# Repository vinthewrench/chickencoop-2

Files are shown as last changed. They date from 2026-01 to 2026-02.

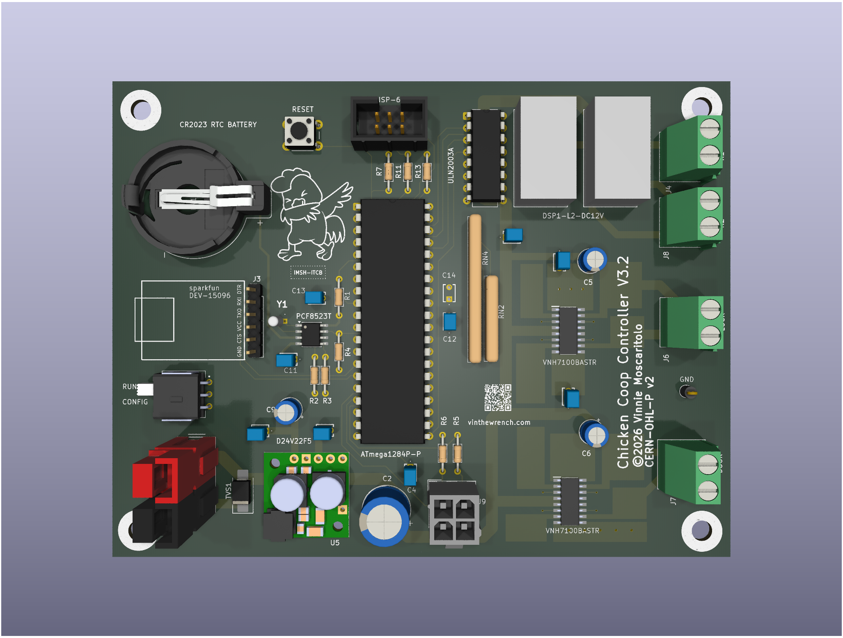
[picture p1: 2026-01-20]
hw/3.2/chickencoop3.2.png

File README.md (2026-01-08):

# Chicken Coop Controller

**Firmware and host-side tooling for an offline, solar-aware chicken coop controller based on the ATmega32U4.**

This repository contains:
- A **desktop host build** for testing and development
- An **AVR firmware build** for deployment
- A shared `src/` tree with no generated artifacts

The build system is intentionally explicit and boring:
- C++ only
- No generated files in `src/`
- All object files live under `build/`
- Host and firmware builds are independent

Hardware for this repository is frozen at **Chicken Coop Controller V3.0**.
Firmware and host code must conform to the shipped hardware.

---

## Repository Layout

```
├── Makefile
│   # Top-level build orchestrator
│   # Invokes host/ and firmware/ builds
│
├── README.md
│   # Project overview and build instructions
│
├── coop.cfg
│   # Example/default runtime configuration for host testing
│
├── firmware/
│   # AVR firmware for Chicken Coop Controller V3.0 (avr-g++)
│   ├── Makefile
│   │   # Firmware build rules
│   ├── main_firmware.cpp
│   │   # Firmware entry point (CONFIG + RUN)
│   │   # Shares scheduler/reducer/apply logic with host
│   └── platform/
│       # Board-specific AVR implementation (Hardware V3.0)
│       ├── config_eeprom.cpp
│       │   # Persistent configuration storage (EEPROM)
│       ├── config_sw_avr.cpp
│       │   # Hardware CONFIG switch handling
│       ├── console_io_avr.cpp
│       │   # AVR-side console I/O glue
│       ├── door_avr.cpp
│       │   # Door motor control (real hardware)
│       ├── door_led_avr.cpp
│       │   # Door LED driver (real hardware)
│       ├── door_lock_avr.cpp
│       │   # Lock actuator control (real hardware)
│       ├── relays_avr.cpp
│       │   # Relay pulse drivers (real hardware)
│       ├── rtc.cpp
│       │   # RTC implementation for PCF8523 (I2C)
│       ├── system_sleep_avr.cpp
│       │   # Low-power sleep implementation (AVR)
│       ├── uart.cpp
│       │   # UART service (console/debug)
│       ├── uart.h
│       ├── uptime.cpp
│       │   # System uptime service (AVR)
│       ├── i2c_avr.cpp
│       │   # I2C implementation (RTC, peripherals)
│       └── i2c.h
│
├── host/
│   # Desktop host build and test console (clang++)
│   ├── Makefile
│   ├── main_host.cpp
│   │   # Host entry point (interactive console + scheduler loop)
│   └── platform/
│       # Host-side implementations (no real hardware)
│       ├── config_host.cpp
│       ├── config_sw_host.cpp
│       ├── console_io_host.cpp
│       ├── door_hw_host.cpp
│       ├── door_led_host.cpp
│       ├── lock_hw_host.cpp
│       ├── relays_host.cpp
│       ├── rtc_host.cpp
│       ├── system_sleep_host.cpp
│       └── uptime_host.cpp
│
└── src/
    # Shared, platform-independent logic
    # No main(), no generated files, minimal platform assumptions
    ├── config.h
    ├── config_common.cpp
    ├── config_events.cpp
    ├── config_events.h
    ├── config_sw.h
    │
    ├── events.h
    ├── resolve_when.cpp
    ├── resolve_when.h
    ├── next_event.cpp
    ├── next_event.h
    │
    ├── rtc.h
    ├── rtc_common.cpp
    │
    ├── solar.cpp
    ├── solar.h
    │
    ├── time_dst.cpp
    ├── time_dst.h
    │
    ├── uptime.h
    │
    ├── scheduler.cpp
    ├── scheduler.h
    ├── state_reducer.cpp
    ├── state_reducer.h
    ├── schedule_apply.cpp
    ├── schedule_apply.h
    │
    ├── system_sleep.h
    │
    ├── door_hw.h
    ├── door_led.h
    ├── lock_hw.h
    ├── relay_hw.h
    │
    ├── console/
    │   # Shared console implementation
    │   ├── console.cpp
    │   ├── console.h
    │   ├── console_cmds.cpp
    │   ├── console_time.cpp
    │   ├── console_time.h
    │   ├── console_io.h
    │   ├── mini_printf.cpp
    │   └── mini_printf.h
    │
    └── devices/
        # Abstract device model layer + state machines
        ├── device.h
        ├── device_ids.h
        ├── devices.cpp
        ├── devices.h
        ├── door_device.cpp
        ├── door_state_machine.cpp
        ├── door_state_machine.h
        ├── lock_device.cpp
        ├── lock_state_machine.cpp
        ├── lock_state_machine.h
        ├── relay_device.cpp
        ├── led_device.cpp
        ├── led_state_machine.cpp
        ├── led_state_machine.h
        └── foo_device.cpp
```

### Rules
- `src/` must always remain clean
- No `.o`, `.elf`, `.hex`, or generated files under `src/`
- All build products live under `build/`
- Host and firmware builds do **not** share object files

---

## Top-Level Make Targets

Run all commands from the **repository root**.

```sh
make
make all
```
Builds **both** host and firmware (default).

```sh
make host
```
Builds **host console only**.

```sh
make firmware
```
Builds **AVR firmware only**.

```sh
make clean
```
Cleans host and firmware build outputs.

---

## Host Console (Desktop Test Environment)

### Purpose
The host build is a functional test harness for:
- Command parsing
- Solar and schedule calculations
- Configuration handling
- Console behavior
- Simulated RTC, EEPROM, relays, door, lock, and uptime

### Build
```sh
cd host
make
```

### Run
```sh
./build/console_host
```

### Exit
```
exit
```

The host build uses **clang++** and builds entirely under `host/build/`.

No source files live under `host/src/`. All shared logic comes from the top-level `src/` directory.

---

## Firmware (ATmega32U4)

### Build
```sh
cd firmware
make
```

### Outputs
```
coop_firmware.elf
coop_firmware.hex
coop_firmware.map
```

### Toolchain
- `avr-g++`
- Target MCU: **ATmega32U4**
- Clock: **Internal 8 MHz RC oscillator**

---

## Flashing (Atmel-ICE, ISP)

```sh
cd firmware
make flash
```

Assumptions:
- Atmel-ICE
- ISP mode
- USB transport
- No bootloader

---

## Fuse Management (LOCKED VALUES)

⚠️ **WARNING**  
Fuse settings are hardware configuration. Treat as write-once per board.

### Read fuses
```sh
cd firmware
make check-fuses
```

### Program fuses (ONLY on new or recovered chips)
```sh
cd firmware
make set-fuses
```

### Locked Fuse Values

| Fuse | Value | Meaning |
|-----:|:-----:|---|
| Low  | 0xFF  | Internal 8 MHz RC, CLKDIV8 disabled |
| High | 0xD8  | JTAG disabled, reset enabled |
| Ext  | 0xF5  | Brown-out detect ≈ 4.3 V |

These values are fixed by the hardware design and should not be changed casually.

---

## Time, Solar, and DST Behavior

- RTC runs in **local civil time**
- `tz` is the **standard time offset** (e.g. `-6` for Central)
- Daylight Saving Time is handled via **US rules (post-2007)**
- DST logic lives in `src/time_dst.cpp`
- DST is applied at the **solar computation boundary**, not inside the solar math itself

This system is fully offline and deterministic.

---

## Version Injection

### Single source of truth
Defined in the **top-level Makefile**:

Note: `PROJECT_VERSION` refers to the **firmware/software version**, not the hardware revision.
Hardware for this repository is **Chicken Coop Controller V3.0**.

```make
PROJECT_VERSION := 2.6.x
```

### Injected into builds as
```c++
PROJECT_VERSION
```

### Used for
- Startup banner
- `version` console command
- Debug output

---

## Sanity Check Workflow

From the repo root:

```sh
make clean
make
make host
make firmware
```

If this completes without errors, the build system is stable.

---

## Final Notes

- GNU Make **3.81 compatible**
- Relative paths used intentionally
- No clever build magic
- If something breaks, it’s real code, not glue

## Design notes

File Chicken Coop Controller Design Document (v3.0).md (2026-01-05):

<style>
@media print {
  body { font-family: Georgia, serif; line-height: 1.5; margin: 2cm; }
 /*h1 { page-break-before: always; } *//* New sections on new pages */
  pre, code { background: #f4f4f4; padding: 10px; }
  hr { page-break-after: always; visibility: hidden; }  /* Use --- for manual breaks */
}
</style>

# Standalone Chicken Coop Controller Design Document (v3.0)

**Date:** Jan 5, 2026  

**Sources of Truth:**  
- KiCad schematic (`chickencoop3.kicad_sch`)  
- Locked MCU pin assignments   

## 1. Purpose and Scope (Goal)

The controller automates chicken coop door operation in off-grid or remote setups by opening the door at **sunrise** and closing/securing it at **sunset**. This protects chickens from nocturnal predators while allowing free-range access during daylight hours.

Core design goals:  
- Fully **offline** — no internet, cloud, GPS, or external sensors.  
- One-time manual setup of date, time, latitude, and longitude by the farmer via serial console.  
- Months-long operation on a single 12V motorcycle-size SLA/AGM battery (typically 7–12 Ah).  
- Deterministic and fully inspectable behavior — all states observable via LED, multimeter, or serial console only.  
- Minimal components for maximum reliability and lowest possible power consumption.  

The system assumes a fixed geographic location and uses local standard time (no automatic DST handling).

## 2. How It Works (High-Level Overview)

1. **Initial Setup**  
   The farmer connects a serial console (e.g., via FTDI adapter) and uses simple text commands to set current date/time, latitude, longitude, and timezone offset. These values are stored persistently in the ATmega32U4 EEPROM.

2. **Normal Operation (RUN Mode)**  
   - The MCU spends >99% of its time in power-down sleep.  
   - It wakes via RTC alarm interrupt or manual door button press.  
   - On wake: reads current date/time from the PCF8523T RTC.  
   - Computes sunrise and sunset times for the current date using the stored location and the ported buelowp/sunset algorithm.  
   - If current time matches sunrise → opens door (extend actuator).  
   - If current time matches sunset → closes door (retract actuator), then pulses lock actuator.  
   - Programs the next RTC alarm (sunrise or sunset) and returns to sleep.  

3. **Manual Override**  
   Pressing the illuminated door button wakes the MCU and toggles the door state (open ↔ close + lock/unlock as needed).

4. **Status Indication**  
   The full-face illumination of the button actuator provides clear visual feedback (motion, locked, config needed, fault).

5. **Power Management**  
   12V battery powers actuators directly. The Pololu D24V22F5 switching regulator provides efficient 5V for logic with very low quiescent current.

Door position is inferred mechanically from the PA-14 actuator’s internal limit switches combined with firmware-enforced maximum runtimes. No external sensors are used.

Firmware is written in AVR C++, interrupt-driven, no RTOS, total size comfortably under 32 KB flash.

## 3. System Overview – Major Components

- **MCU**: ATmega32U4RC-AU (TQFP-44, internal RC oscillator)  
- **RTC**: PCF8523T (SOIC-8, I2C, alarm interrupt, CR2032 backup, 32.768 kHz crystal AB26T-32.768kHz)  
- **Door Actuator**: PA-14 linear actuator (12 V, internal non-adjustable limit switches)  
- **Lock Actuator**: Generic 12 V automotive door lock actuator (time-pulsed only)  
- **Motor Drivers**: 2 × VNH7100BASTR (INA/INB/EN control)  
- **5 V Regulator**: Pololu D24V22F5 (step-down switching regulator, 5.3–36 V input, 5 V @ up to 2.5 A output)  
- **Battery**: 12 V motorcycle-size sealed lead-acid or AGM  
- **User Interface / Status Indicator**: FL12DRG5 (EOZ) illuminated momentary pushbutton  
  - Integrates SPST-NO switch contact and full-face bi-color (red/green) LED at 5 V.  
  - Panel-mount (12 mm cutout), IP67 sealed, off-board via cable.

## 4. Power Architecture

- **Direct 12 V paths**: Battery → actuators (via motor drivers).  
- **5 V rail**: Pololu D24V22F5  
  - Input range: 5.3–36 V (ideal for 12 V SLA/AGM with charging margin).  
  - Output: 5 V @ up to 2.5 A.  
  - Quiescent current: ~1 mA (enabled).  
  - EN pin: Left unconnected (internal 270 kΩ pull-up to VIN keeps regulator enabled).  
  - Built-in protections: reverse-voltage, over-current, thermal shutdown.  

- **Sleep optimization**: Regulator remains enabled (EN floating). MCU enters power-down mode, achieving overall sleep current dominated by regulator's ~1 mA (acceptable for months-long battery life on 7–12 Ah capacity).  

- **Additional Recommended Components** (around D24V22F5):  
  - Input: 33–47 µF electrolytic (≥50 V) + 0.1–10 µF ceramic between VIN and GND (close to pins) for noise suppression on long battery leads.  
  - Output: 10–47 µF low-ESR capacitor (≥10 V) between VOUT and GND for load stability.  
  - PG pin: Optional 10–100 kΩ pull-up to +5 V if monitoring Power Good.  

- **Protection**:  
  - 5 A resettable polyfuse in series with battery positive.  
  - Reverse polarity protection built into D24V22F5.  

Target total sleep current: ~1 mA (yielding months of operation on a 7–12 Ah battery).

## 5. MCU Details and Locked Pin Assignments

**MCU Part Number**: ATmega32U4 (RC variant for internal oscillator)  
**Package**: 44-pin TQFP  
**Voltage**: 5 V  
**Source of truth for pinout**: Microchip Atmel-7766 Figure 1-1  

**MCU Specs**  
- Flash: 32 KB  
- SRAM: 2.5 KB  
- EEPROM: 1 KB  
- Clock: Internal RC  
- Voltage: 5 V  

**Locked Design Decisions**  
- Programming: AVR-ISP-6 only  
- USB: Not used (connector not populated, D+/D- NC)  
- RTC wake: External interrupt  
- Serial console: UART (USART1)  
- Door and lock drivers: 2 × VNH7100BASTR  
- All references use **physical pin numbers**  

**Boot/USB/Recovery**  
- Reflash method: ISP only (no DFU reliance)  
- HWB (PE2, Pin 33): Pulled HIGH (10 kΩ) to prevent accidental bootloader entry  

**Power Pins**  
- Pin 2: UVcc (USB supply – not used)  
- Pin 5: UGnd  
- Pin 6: UCap (USB regulator cap)  
- Pin 7: VBus (USB sense – NC)  
- Pin 14: VCC  
- Pin 15: GND  
- Pin 23: GND  
- Pin 24: AVCC  
- Pin 34: VCC  
- Pin 35: GND  
- Pin 42: AREF  
- Pin 43: GND  
- Pin 44: AVCC  
- Pin 13: RESET  

**Decoupling (Required)**  
- 0.1 µF ceramic at each supply pin group (VCC/AVCC/UVCC) placed close to MCU.  
- At least one local bulk capacitor (4.7–10 µF) near MCU supply.  

**Pin Assignments**

### ISP (AVR-ISP-6)
| Signal | Physical Pin | Port/Function |
|---|---|---|
| SCK | 9 | PB1 |
| MOSI | 10 | PB2 |
| MISO | 11 | PB3 |
| RESET  | 13 | RESET |
| VCC | 14 | VCC |
| GND | 15 | GND |

### I2C (PCF8523T RTC)
| Signal | Physical Pin | Port/Function | Notes |
|---|---|---|---|
| SCL | 18 | PD0 | 4.7 kΩ pull-up to +5 V |
| SDA | 19 | PD1 | 4.7 kΩ pull-up to +5 V |

**I2C Pull-ups**  
If the PCF8523T module has no built-in pull-ups, add 4.7 kΩ to +5 V on SCL/SDA.

### RTC Wake Interrupt
| Signal | Physical Pin | Port/Function | Notes |
|---|---|---|---|
| RTC_INT  | 12 | PB7 | 10 kΩ pull-up to VCC |

### Serial Console (e.g., SparkFun DEV-15096 compatible)
| Physical Pin | Port/Function | SparkFun Pin | Notes |
|---|---|---|---|
| 20 | PD2 / RXD1 | 3 (TXO) | Optional 1 kΩ series |
| 21 | PD3 / TXD1 | 2 (RXI) | Optional 1 kΩ series |
| GND | GND | 6 | |

No DTR, CTS, or VCC connection.

### Configuration Switch

| Signal | Physical Pin | Port/Function | Notes |
|---|---|---|---|
| CONGIG_SW  | 31 | PC6 | 10 kΩ pull-up to VCC |

- SPDT switch (one throw to GND, other NC)  
- Internal pull-up enabled  
- Sampled once at boot

### Door Pushbutton and Integrated Status LED (FL12DRG5)
**Part**: FL12DRG5 (EOZ illuminated momentary pushbutton, bi-color red/green, 5 V fixed LED).    
 - Test shows that @5v - 240Ω series,  Red  = ~11mA, Green = ~9ma

**Implementation**  
- The FL12DRG5 is mounted on the enclosure panel and connected to the PCB via a **4-pin cable and connector**.  
- This single part provides both the manual door override button **and** the sole status indicator (full-face illuminated actuator).  
- No separate status LED or dedicated LED driver is used.

**Connections** (via 4-pin connector/cable):
| Signal | MCU Pin (Physical) | Port | Notes |
|---|---|---|---|
| Switch signal (NO)  | Pin 28 | PB4  | Active low to GND, 220 Ω series + 0.1 µF debounce on PCB |
| Common GND | — | GND  | Shared for switch and LED cathode |
| Red LED anode | Pin 29 | PB5  | Direct drive (built-in limiting resistors) |
| Green LED anode | Pin 30 | PB6  | Direct drive (built-in limiting resistors) |

**Button Function**  
- Momentary press wakes MCU (PCINT7) and toggles door state (open ↔ close + lock/unlock as needed).

**LED Behavior** (full-face illumination of button actuator)  
Priority (highest first):

| Priority | Condition | LED Pattern (Button Face) | Meaning |
|---|---|---|---|
| 1 | Fault | Solid RED | Actuator timeout, invalid state, etc. |
| 2 | Config required | Solid YELLOW (red + green) | No valid location/date in EEPROM |
| 3 | Door motion | Blink @ 2 Hz:<br>• **RED** = closing<br>• **GREEN** = opening | Clear directional feedback |
| 4 | Door closed + locked | RED pulse every 15 s (20–30 ms on) | Nighttime confirmation |
| 5 | Idle (door open, daytime)  | LEDs completely OFF | Power saving |

This integrated approach reduces component count, wiring, and power draw while providing highly visible, directional status feedback directly on the button the farmer presses.

### VNH7100BASTR Motor Drivers
**Lock Driver**
| Signal | Physical Pin | Port |
|---|---|---|
| LOCK_INA | 41 | PF0  |
| LOCK_INB | 40 | PF1  |
| LOCK_EN  | 39 | PF4  |

**Door Driver**
| Signal | Physical Pin | Port |
|---|---|---|
| DOOR_INA | 38 | PF5  |
| DOOR_INB | 37 | PF6  |
| DOOR_EN  | 36 | PF7  |

**Relay Drivers (Optional)**
| Signal | Physical Pin | Port |
|---|---|---|
| RELAY_1_SET | 22 | PD5  |
| RELAY_1_RESET | 25 | PD4  |
| RELAY_2_SET | 26 | PD6  |
| RELAY_2_RESET | 27 | PD7  |

Notes:  
- PF pins require AVCC powered.  
- JTAG disabled (fuses) to free PF4–PF7.  
- Default firmware state: EN = 0, INA/INB = 0.

### Complete Pin Assignment Table
| Pin # | Port / Signal | Assigned Function |
|---|---|---|
| 1 | PE6 | Unused |
| 2 | UVcc | USB supply (not used) |
| 3 | D- | USB (NC) |
| 4 | D+ | USB (NC) |
| 5 | UGnd | USB ground |
| 6 | UCap | USB regulator cap |
| 7 | VBus | USB sense (NC) |
| 8 | PB0 | Unused |
| 9 | PB1 | ISP SCK |
| 10 | PB2 | ISP MOSI |
| 11 | PB3 | ISP MISO |
| 12 | PB7 | RTC_INT (INT6) |
| 13 | RESET | RESET |
| 14 | VCC | +5 V |
| 15 | GND | Ground |
| 16 | XTAL2 | Unused (RC clock) |
| 17 | XTAL1 | Unused (RC clock) |
| 18 | PD0 | I2C SCL |
| 19 | PD1 | I2C SDA |
| 20 | PD2 | UART RXD1 |
| 21 | PD3 | UART TXD1 |
| 22 | PD5 | RELAY_1_RESET |
| 23 | GND | Ground |
| 24 | AVCC | Analog supply |
| 25 | PD4 | RELAY_1_SET |
| 26 | PD6 | RELAY_2_SET |
| 27 | PD7 | RELAY_2_RESET |
| 28 | PB4 | DOOR_SW (FL12DRG5 switch) |
| 29 | PB5 | Red LED anode (FL12DRG5) |
| 30 | PB6 | Green LED anode (FL12DRG5) |
| 31 | PC6 | CONFIG_SW |
| 32 | PC7 | Unused |
| 33 | PE2 | HWB (pulled high) |
| 34 | VCC | +5 V |
| 35 | GND | Ground |
| 36 | PF7 | DOOR_EN |
| 37 | PF6 | DOOR_INB |
| 38 | PF5 | DOOR_INA |
| 39 | PF4 | LOCK_EN |
| 40 | PF1 | LOCK_INB |
| 41 | PF0 | LOCK_INA |
| 42 | AREF | Analog reference |
| 43 | GND | Ground |
| 44 | AVCC | Analog supply |

## 6. Sunrise/Sunset Computation

Algorithm ported from **buelowp/sunset** (https://github.com/buelowp/sunset – Mike Chirico’s sunrise.c).

- Inputs: year, month, day, latitude (signed decimal degrees), longitude (signed), manual timezone offset (hours).  
- Core calculations: Julian day → solar declination → equation of time → hour angle → local sunrise/sunset times.  
- Output: minutes past midnight for sunrise and sunset.  
- Porting notes for AVR:  
  - Use double-precision floating point (soft-float supported by avr-gcc).  
  - Or convert to fixed-point for smaller code/size if needed.  
  - Accuracy ±2–5 minutes (more than sufficient for coop use).  
  - Handles edge cases (polar day/night returns invalid → no event).  

## 7. Persistent Storage

Latitude, longitude, timezone offset, and initial date/time are stored in the **ATmega32U4’s 1 KB EEPROM** for persistence across full power loss.

## 8. RTC and Timekeeping

- PCF8523T runs continuously on CR2032 backup when main battery is removed.  
- Sole source of truth for date/time.  
- Firmware sets single alarm interrupt for next sunrise or sunset event.

## 9. Actuator Control Logic

- **Door (PA-14)**: Enable driver, set INA/INB direction, run until firmware timeout (suggested 30 s max) or internal limits stop current.  
- **Lock**: Enable driver, set direction, pulse 150–400 ms (max 500 ms), disable. Never left energized.  

Default driver state: EN = 0, INA/INB = 0.

## 10. Boot and Configuration

- Boot samples CONFIG_SW (PB4).  
- Grounded → CONFIG mode (serial console active).  
- Open → RUN mode.  
- CONFIG commands (text, 115200 8N1 suggested):  
  - `set date YYYY-MM-DD`  
  - `set time HH:MM:SS`  
  - `set lat ±DD.DDDD`  
  - `set long ±DDD.DDDD`  
  - `set tz ±HH` (timezone offset)  
  - `open` / `close` / `lock` / `unlock` (manual test)  
- 60 s inactivity → auto-enter RUN mode.

## 11. Sleep Strategy

- MCU in power-down mode.  
- Wake sources: RTC INT (PE6), door button (PB7/PCINT).  
- All unnecessary peripherals disabled.  
- Regulator remains enabled (EN floating).  

## 12. Bill of Materials (Key Electrical Items)

- ATmega32U4RC-AU  
- PCF8523T  
- 2 × VNH7100BASTR  
- Pololu D24V22F5 (5 V step-down regulator)  
- AB26T-32.768kHz crystal  
- CR2032 + holder  
- FL12DRG5 (EOZ) — illuminated momentary pushbutton, bi-color red/green, 5 V  
- Passives: resistors (4.7 k, 10 k, 220 Ω, etc.), capacitors (input/output for regulator, 0.1 µF decoupling ceramics, bulk caps), polyfuse  

## 13. Explicit Exclusions

- No sensors  
- No wireless  
- No cloud/GPS  
- No automatic DST  
- No encoders/feedback  
- No heartbeat LED  
- No separate status LED or LED driver IC  

## 14. Design Philosophy

If a state or behavior is not directly observable with an LED, multimeter, or serial console — it does not belong in this system.

Minimalism, inspectability, and battery life take priority over convenience features.

## 15. Firmware Overview (AVR C++)

Firmware is written in **AVR C++** (not plain C), compiled with **avr-gcc** (g++ mode), programmed via **Atmel-ICE (ISP mode)**, and built using a **Makefile**. No Arduino framework or libraries are used.

### Key Firmware Requirements
- Ultra-low power: MCU spends >99% of time in power-down sleep.
- Interrupt-driven only: No polling loops.
- Deterministic behavior: All actions triggered by RTC alarm or button press.
- Persistent configuration: Latitude, longitude, timezone offset stored in EEPROM (with CRC validation).
- Sunrise/sunset calculation using fixed-point port of buelowp/sunset algorithm.
- Simple text-based serial console in CONFIG mode.

### Startup Sequence (main() and Initialization)
```cpp
int main(void) {
    // 1. Disable watchdog (in case of previous reset)
    wdt_disable();

    // 2. Disable all unnecessary peripherals to minimize power
    PRR = (1 << PRTWI) | (1 << PRTIM0) | (1 << PRTIM1) | (1 << PRTIM2) |
          (1 << PRADC) | (1 << PRUSART0) | (1 << PRSPI);  // Keep USART1 for console

    // 3. Configure pins
    // Inputs with pull-ups
    DDRB &= ~((1 << PB7) | (1 << PB4));  // DOOR_SW and CONFIG_SW as inputs
    PORTB |= (1 << PB7) | (1 << PB4);    // Enable internal pull-ups

    // Outputs default low/off
    DDRB |= (1 << PB5) | (1 << PB6);     // LED control (red/green)
    DDRF |= (1 << PF7) | (1 << PF6) | (1 << PF5) |   // Door driver
            (1 << PF4) | (1 << PF1) | (1 << PF0);    // Lock driver
    PORTB &= ~((1 << PB5) | (1 << PB6));  // LEDs off
    PORTF &= ~((1 << PF7) | (1 << PF6) | (1 << PF5) |
               (1 << PF4) | (1 << PF1) | (1 << PF0));  // Drivers disabled

    // 4. Sample CONFIG_SW once (latched until reboot)
    bool config_mode = (PINB & (1 << PB4)) == 0;

    // 5. Initialize UART (only if config mode, but safe to init always)
    uart_init(115200);

    // 6. Initialize I2C and RTC
    i2c_init();
    rtc_init();  // Verify communication, set 32kHz output if needed

    // 7. Enable interrupts for wake sources
    PCICR |= (1 << PCIE0);        // Enable pin change interrupt on PCINT[7:0] (PB7)
    PCMSK0 |= (1 << PCINT7);      // Mask for PB7 (door button)
    EIMSK |= (1 << INT6);         // Enable INT6 on PE6 (RTC alarm)
    EIFR |= (1 << INTF6);         // Clear any pending flag

    sei();  // Global interrupt enable

    if (config_mode) {
        enter_config_mode();  // Blocking console loop with inactivity timeout
        // On exit: falls through to RUN mode
    }

    // 8. Load settings from EEPROM (validate with CRC)
    load_settings_from_eeprom();

    // 9. Enter normal RUN mode
    run_mode_loop();  // Never returns
}
```
### Sleep and Wake Strategy
```cpp
void enter_sleep() {
    // Turn off LEDs and drivers
    PORTB &= ~((1 << PB5) | (1 << PB6));
    PORTF &= ~((1 << PF7) | (1 << PF6) | (1 << PF5) |
               (1 << PF4) | (1 << PF1) | (1 << PF0));

    // Additional power reduction
    PRR |= (1 << PRTWI) | (1 << PRUSART1);  // Disable I2C & UART after use

    set_sleep_mode(SLEEP_MODE_PWR_DOWN);
    sleep_enable();
    sei();              // Ensure interrupts enabled before sleep
    sleep_cpu();        // Enter sleep — wakes on RTC INT or button PCINT
    sleep_disable();    // On wake

    // Re-enable peripherals as needed
    PRR &= ~((1 << PRTWI) | (1 << PRUSART1));
}
```
### RUN Mode Main Loop
```cpp
void run_mode_loop() {
    while (1) {
        // Read current date/time from RTC
        rtc_get_datetime(&current_time);

        // Compute sunrise/sunset for today
        compute_sunrise_sunset(current_time.year, current_time.month, current_time.day,
                               settings.lat, settings.lon, settings.tz,
                               &sunrise_min, &sunset_min);

        // Determine next event and program RTC alarm
        uint16_t next_alarm_min;
        if (should_open_now(&current_time, sunrise_min)) {
            open_door();
            next_alarm_min = sunset_min;
        } else if (should_close_now(&current_time, sunset_min)) {
            close_door_and_lock();
            next_alarm_min = sunrise_min;  // Tomorrow's sunrise
        } else {
            // Determine which is next
            next_alarm_min = closer_event(current_time.minutes_past_midnight(),
                                          sunrise_min, sunset_min);
        }

        rtc_set_alarm(next_alarm_min);

        // Update LED state (e.g., pulse if locked)
        update_status_led();

        enter_sleep();  // Sleep until next alarm or button press
    }
}
```
### Interrupt Service Routines
```cpp
ISR(INT6_vect) {
    // RTC alarm — cleared automatically by reading status register
    // Just wake — main loop handles action
}

ISR(PCINT0_vect) {
    if ((PINB & (1 << PB7)) == 0) {  // Button pressed (active low)
        // Debounce in main loop or simple delay
        manual_door_toggle();
    }
}
```
### Key Notes (Firmware)
- All heavy work (sunrise/sunset calculation, actuator drive, LED updates) is performed immediately after wake — the system returns to sleep as soon as possible.
- Serial console is active only in CONFIG mode (or optionally in background if needed for debugging).
- Faults are indicated via LED blink patterns (e.g., solid red on actuator timeout or RTC error).
- Avoid floating-point math if possible — use fixed-point arithmetic for the sunrise/sunset algorithm to reduce code size and execution time on the AVR.
- EEPROM writes are minimized: only on configuration changes (rare) to prevent wear.
- Power reduction registers (PRR) are used aggressively to disable unused peripherals before sleep.
- Interrupt service routines are kept minimal — heavy logic stays in the main loop for readability and debugging.

## 16. Technical Review (Deep Dive – v2.3)

This section provides a detailed technical review of the design as documented in v2.3. All claims are based on datasheets, calculations, and practical experience with similar systems.

### MCU and Pin Assignments
- **ATmega32U4RC-AU**: Excellent choice for low-power, offline work. Internal RC oscillator avoids external crystal power draw (~µA savings). Power-down sleep with PCINT and external interrupt enabled draws ~0.1–1 µA (datasheet Table 29-1).  
- **Pin usage**: Fully locked and conflict-free. PF4–PF7 freed by JTAG disable (fuses). Unused pins (PD4–PD7, PC6–PC7, PB0) should be configured as outputs low or inputs pull-up disabled to minimize leakage.  
- **Fuses recommended**:  
  - Low: 0xFF (8 MHz internal RC, no CLKDIV8)  
  - High: 0xD8 (JTAG disabled, boot size 0)  
  - Extended: 0xF5 (BOD ~4.3 V for 5 V stability)  
- **Risk**: No ADC used — disable in PRR to save ~100 µA potential. Internal RC calibration drift ±10% — irrelevant for timing (RTC is master).

### Power Architecture (Pololu D24V22F5)
- **Performance**: Synchronous buck, ~90–95% efficiency at 12 V → 5 V. Quiescent ~1 mA enabled (datasheet typical). EN floating = correct (internal pull-up).  
- **External caps**: Input 33–47 µF electrolytic + 0.1–10 µF ceramic recommended for long battery wires/actuator spikes. Output 10–47 µF low-ESR for transients.  
- **Sleep current**: Regulator dominates at ~1 mA → 720 mAh/month. On 7 Ah battery: ~9–10 months. On 12 Ah: 16+ months. Acceptable for goal.  
- **Protection**: Built-in reverse (-40 V), overcurrent, thermal. Polyfuse + optional SMAJ18A TVS on +12 V adds belt-and-suspenders.  
- **Alternative for lower quiescent**: TPS62825 (~4 µA) would extend life significantly, but D24V22F5 is proven and fits footprint—stick with it unless measured sleep >1.5 mA.

### RTC (PCF8523T)
- **Accuracy**: ±20 ppm crystal → ~1–2 min/year drift. Chickens don't care—sufficient.  
- **Backup**: CR2032 lasts 5–10 years at 0.5 µA.  
- **I2C**: Pull-ups 4.7 kΩ fine. Bus short traces to avoid capacitance issues.  
- **Wake**: INT1 to PE6 (INT6) perfect—level-sensitive in power-down.

### Sunrise/Sunset Algorithm
- **Port**: buelowp/sunset is solid NOAA-based. Fixed-point recommended for AVR (no FPU). Execution <10 ms. Accuracy ±2–5 min — more than enough.  
- **Edge cases**: Polar latitudes handled (return invalid → skip event).  
- **Optimization**: Precompute declination table in flash if flash space allows.

### Startup and Power-Restore Behavior

On startup or power restore, the system does not replay missed scheduled events.

Instead, the system computes the desired steady state for the current time based on the active configuration and converges to that state immediately.

This reconciliation process ensures safe, deterministic behavior and prevents unintended actuation caused by delayed or missed events.

For example:

If the configured door open time has passed but the close time has not, the door will be commanded open.

If the configured close time has passed, the door will be commanded closed, regardless of whether the open event was missed.

Past events are never retroactively executed. Only the correct state for the present time is enforced.

This behavior is by design and applies uniformly to all time-scheduled subsystems.

On startup or power restore, the system does not replay missed events.
It computes the desired steady state for the current time and converges to it.

### User Interface (FL12DRG5)
- **Integration**: Brilliant minimalism—one part for button + status. Full-face illumination highly visible.  
- **Current**: Built-in resistors ~10–20 mA/color. Patterns low-duty → average <<1 mA. Direct MCU drive safe (pins rated 20 mA recommended).  
- **Wiring**: 4-pin cable clean for panel mount. IP67 front seal perfect for coop.  
- **Risk**: Exact current unknown until measured—test sample and add series resistors if too bright/power-hungry.

### Actuator Control (VNH7100BASTR)
- **Capability**: Handles PA-14 stall (~1–2 A) and lock pulse easily. EN control allows clean off-state.  
- **Inference**: Mechanical limits + timeout = reliable without sensors.  
- **Risk**: Stuck actuator undetected—LED fault blink covers it (timeout triggers fault).

### Persistent Storage
- **EEPROM**: 1 KB plenty. Writes only on config changes → <10/year → zero wear concern.

### Sleep Strategy
- **Power-down**: Dominant draw is regulator ~1 mA. MCU/RTC/drivers negligible.  
- **Wake**: RTC INT + button PCINT — ideal. No polling.

### Firmware (AVR C++)
- **Build chain**: avr-gcc (g++), Makefile, Atmel-ICE ISP — clean, reproducible, no bloat.  
- **Structure**: Interrupt-driven, sleep-centric — correct for power.  
- **Robustness**: Add CRC on EEPROM read, timeout faults to LED.

### Overall Assessment
- **Strengths**: Minimal, inspectable, deterministic, low-power enough for goal.  
- **Weaknesses**: Regulator quiescent limits life to ~9–16 months (still fine). No over-the-air recovery if firmware bug (but ISP header allows field fix).  
- **Score**: 9/10 — production-ready after first-board test (focus on sleep current measurement and LED brightness).  

No showstoppers. Build the PCB.

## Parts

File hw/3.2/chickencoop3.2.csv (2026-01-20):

Id | Designator | Footprint | Quantity | Designation | Supplier and ref
1 | BT1 | BAT_1066 | 1 | 1066
2 | C13,C1,C10,C11,C7,C12,C3,C4,C8,C14 | RCER71H104K0DBH03A | 10 | .1uf
3 | R4,R1 | R_Axial_DIN0204_L3.6mm_D1.6mm_P7.62mm_Horizontal | 2 | 10K
4 | U4,U3 | SOIC127P600X175-16N | 2 | VNH7100BASTR
5 | C5,C6,C9 | CP_Radial_D5.0mm_P2.00mm | 3 | 47uf
6 | J4 | TerminalBlock_Phoenix_MKDS-1,5-2-5.08_1x02_P5.08mm_Horizontal | 1 | K1
7 | TP3 | 5000 | 1 | GND
8 | RN2 | R_Array_SIP7 | 1 | 100K
9 | J3 | PinHeader_1x06_P2.54mm_Vertical | 1 | Serial port
10 | U1 | DIP-40_W15.24mm | 1 | ATmega1284P-P
11 | U5 | MODULE_5V_2.5A_STEP-DOWN_D24V22F5 | 1 | D24V22F5
12 | R5 | R_Axial_DIN0204_L3.6mm_D1.6mm_P7.62mm_Horizontal | 1 | 240Ω
13 | R3 | R_Axial_DIN0204_L3.6mm_D1.6mm_P7.62mm_Horizontal | 1 | 4.7K
14 | RN4 | R_Array_SIP12 | 1 | 1K
15 | K2,K1 | DSP1-L2-DC12V | 2 | DSP1-L2-DC12V
16 | C2 | CP_Radial_D10.0mm_P5.00mm | 1 | 1000uf
17 | R13,R11,R7 | R_Axial_DIN0204_L3.6mm_D1.6mm_P7.62mm_Horizontal | 3 | 470Ω
18 | U2 | SOIC-8_3.9x4.9mm_P1.27mm | 1 | PCF8523T
19 | J8 | TerminalBlock_Phoenix_MKDS-1,5-2-5.08_1x02_P5.08mm_Horizontal | 1 | K2
20 | R2 | R_Axial_DIN0204_L3.6mm_D1.6mm_P7.62mm_Horizontal | 1 | 4.7k
21 | TVS1 | D_SMB_Handsoldering | 1 | P6SMB18A
22 | J7 | TerminalBlock_Phoenix_MKDS-1,5-2-5.08_1x02_P5.08mm_Horizontal | 1 | DOOR
23 | J9 | Molex_Mini-Fit_Jr_5566-04A_2x02_P4.20mm_Vertical | 1 | Mini‑Fit Jr
24 | R6 | R_Axial_DIN0204_L3.6mm_D1.6mm_P7.62mm_Horizontal | 1 | 220Ω
25 | J1 | powerpole | 1 | Power Pole
26 | J6 | TerminalBlock_Phoenix_MKDS-1,5-2-5.08_1x02_P5.08mm_Horizontal | 1 | LOCK
27 | SW1 | AS11CH | 1 | SW_SPST
28 | SW3 | SW_PUSH_6mm | 1 | RESET
29 | J2 | PinHeader_2x03_P2.54mm_Vertical | 1 | AVR-ISP-6
30 | Y1 | AB26T32768KHZ | 1 | AB26T-32.768KHZ
31 | U6 | DIP-16_W7.62mm | 1 | ULN2003A

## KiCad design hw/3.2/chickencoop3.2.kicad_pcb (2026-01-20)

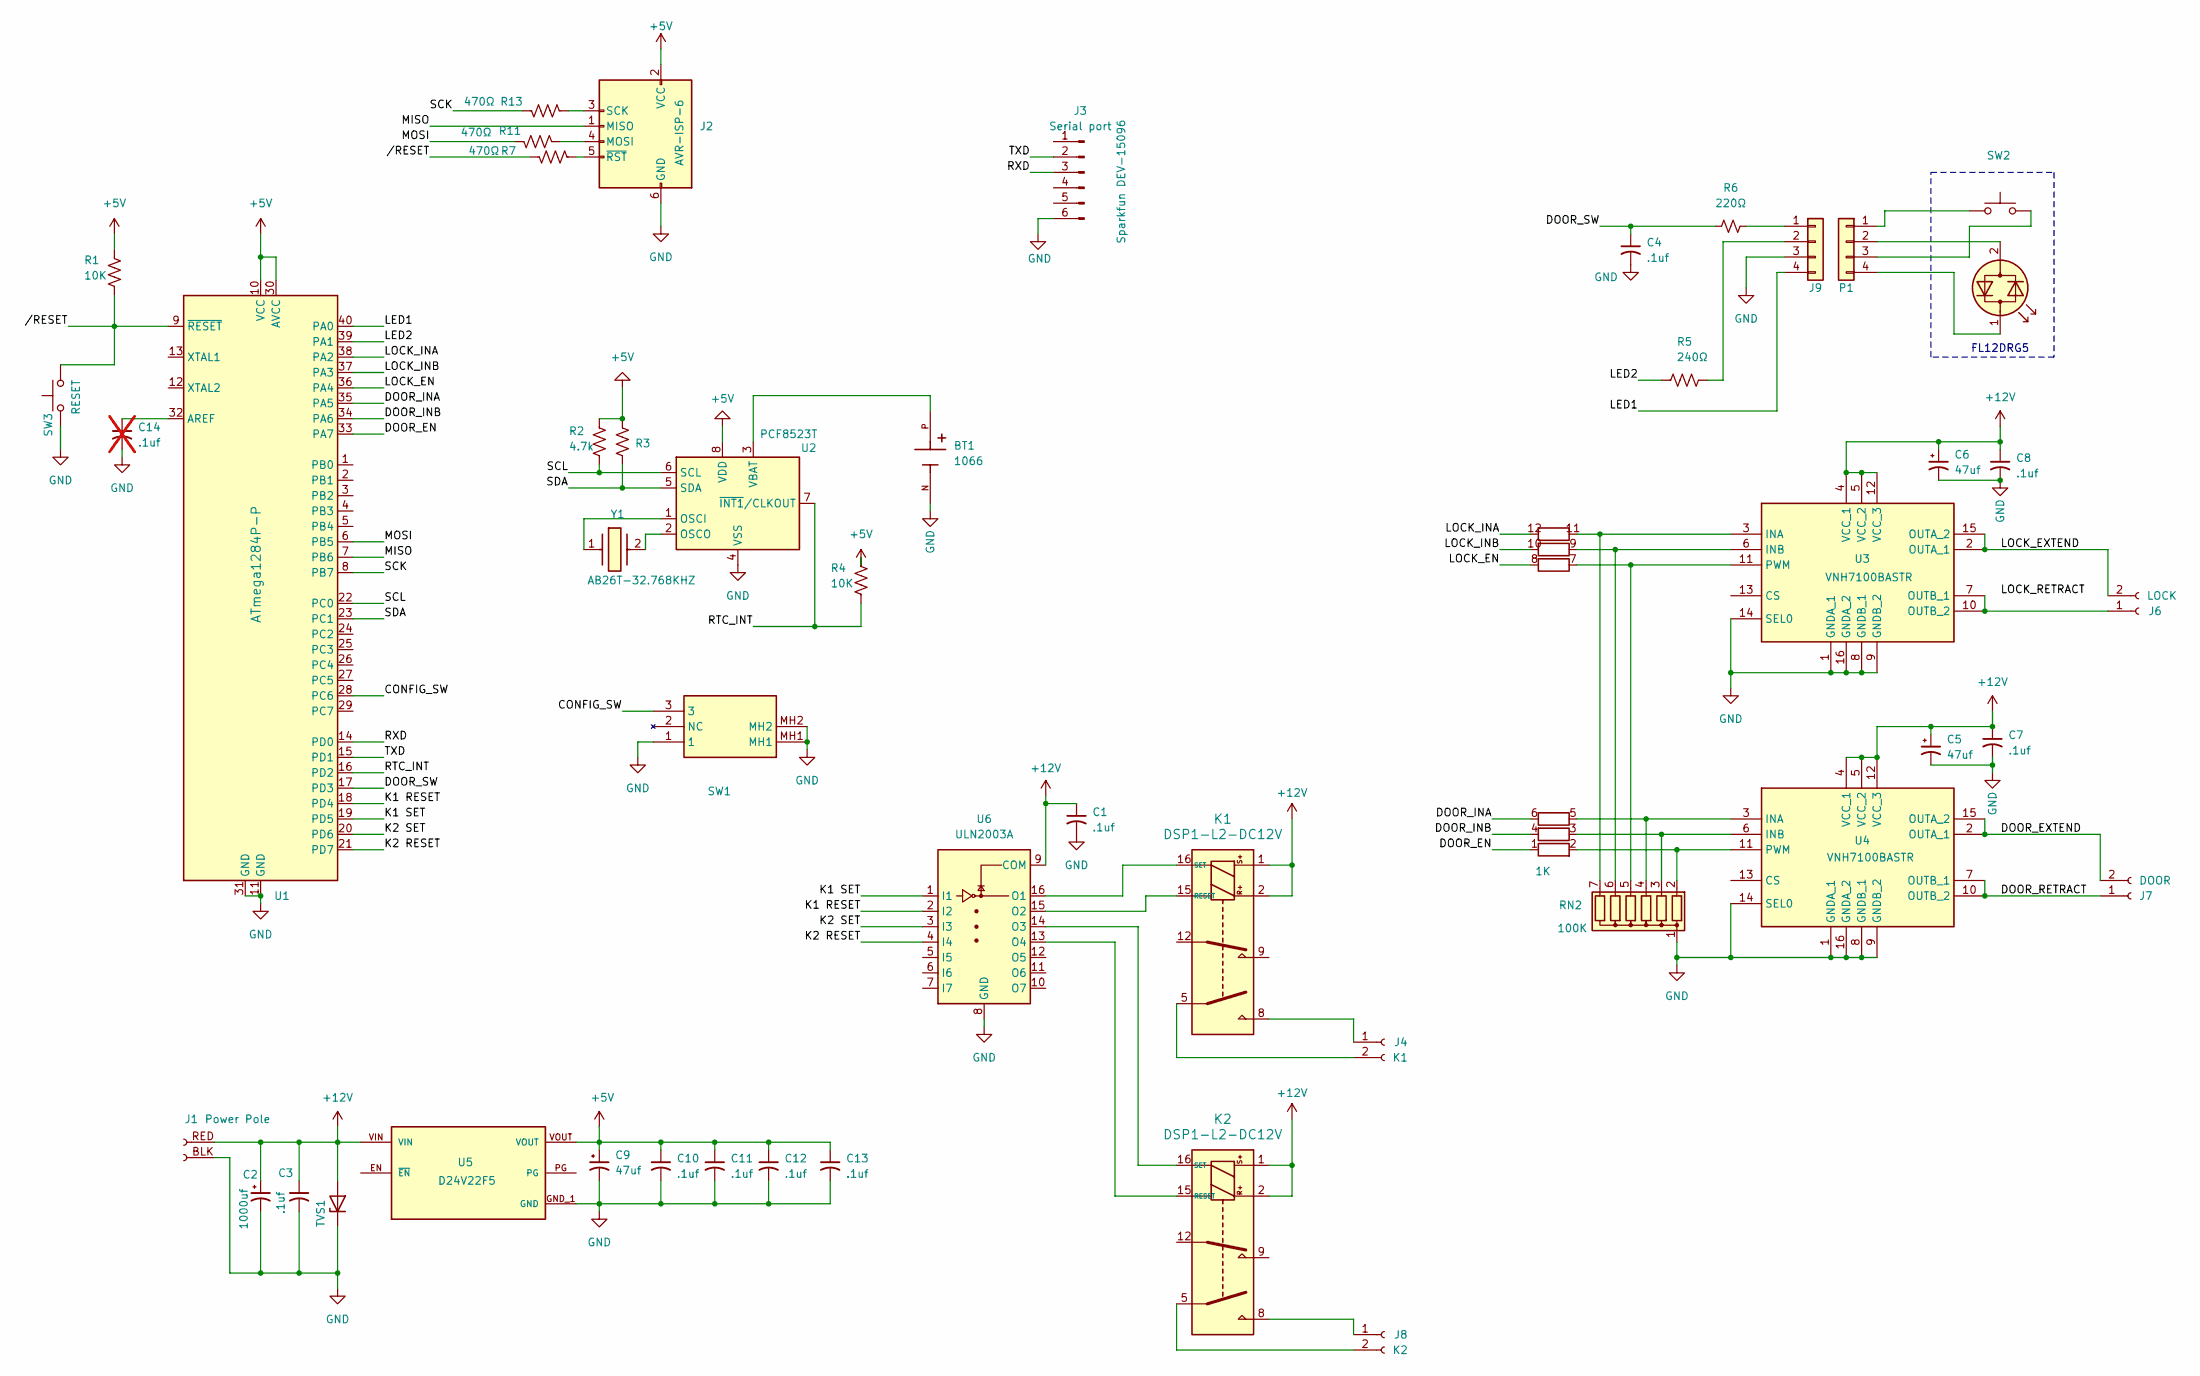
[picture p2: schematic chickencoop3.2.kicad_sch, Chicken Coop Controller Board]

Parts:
BT1: 1066; BAT_1066; PARTREV E
C1, C3, C4, C7, C8, C10, C11, C12, C13: .1uf; RCER71H104K0DBH03A
C2: 1000uf; CP_Radial_D10.0mm_P5.00mm
C5, C6, C9: 47uf; CP_Radial_D5.0mm_P2.00mm
C14: .1uf; RCER71H104K0DBH03A; not fitted
D1: LED_Dual_Bidirectional
J1: Power Pole; powerpole
J2: AVR-ISP-6; PinHeader_2x03_P2.54mm_Vertical
J3: Serial port; PinHeader_1x06_P2.54mm_Vertical
J4: K1; TerminalBlock_Phoenix_MKDS-1,5-2-5.08_1x02_P5.08mm_Horizont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
J6: LOCK; TerminalBlock_Phoenix_MKDS-1,5-2-5.08_1x02_P5.08mm_Horizont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
J7: DOOR; TerminalBlock_Phoenix_MKDS-1,5-2-5.08_1x02_P5.08mm_Horizont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
J8: K2; TerminalBlock_Phoenix_MKDS-1,5-2-5.08_1x02_P5.08mm_Horizont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
J9: Mini‑Fit Jr; Molex_Mini-Fit_Jr_5566-04A_2x02_P4.20mm_Vertical
K1, K2: DSP1-L2-DC12V
P1: Mini‑Fit Jr; Molex_Mini-Fit_Jr_5566-04A_2x02_P4.20mm_Vertical
R1, R4: 10K; R_Axial_DIN0204_L3.6mm_D1.6mm_P7.62mm_Horizontal
R2: 4.7k; R_Axial_DIN0204_L3.6mm_D1.6mm_P7.62mm_Horizontal
R3: 4.7K; R_Axial_DIN0204_L3.6mm_D1.6mm_P7.62mm_Horizontal
R5: 240Ω; R_Axial_DIN0204_L3.6mm_D1.6mm_P7.62mm_Horizontal
R6: 220Ω; R_Axial_DIN0204_L3.6mm_D1.6mm_P7.62mm_Horizontal
R7, R11, R13: 470Ω; R_Axial_DIN0204_L3.6mm_D1.6mm_P7.62mm_Horizontal
RN2: 100K; R_Array_SIP7; Manufacturer_Part_Number 4607X-101-104LF
RN4: 1K; R_Array_SIP12; Manufacturer_Part_Number 4612X-102-102LF
SW1: SW_SPST; AS11CH; Mouser Part Number 633-AS11CH
SW2: SW_Push
SW3: RESET; SW_PUSH_6mm
TVS1: P6SMB18A; D_SMB_Handsoldering
U1: ATmega1284P-P; DIP-40_W15.24mm
U2: PCF8523T; SOIC-8_3.9x4.9mm_P1.27mm
U3, U4: VNH7100BASTR; SOIC127P600X175-16N; Manufacturer_Part_Number VNH7100BASTR; Mouser Part Number 511-VNH7100BASTR
U5: D24V22F5; MODULE_5V_2.5A_STEP-DOWN_D24V22F5; PARTREV 12 November 2015
U6: ULN2003A; DIP-16_W7.62mm
Y1: AB26T-32.768KHZ; AB26T32768KHZ; Mouser Part Number 815-AB26T-32.768KHZ

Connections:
+5V: C9.1, C10.1, C11.1, C12.1, C13.1, J2.2 (VCC), R1.1, R2.1, R3.1, R4.1, U1.10 (VCC), U1.30 (AVCC), U2.8 (VDD), U5.VOUT
+12V: C1.1, C2.1, C3.1, C5.1, C6.1, C7.1, C8.1, J1.RED, K1.1, K1.2, K2.1, K2.2, TVS1.2 (A), U3.4 (VCC_1), U3.5 (VCC_2), U3.12 (VCC_3), U4.4 (VCC_1), U4.5 (VCC_2), U4.12 (VCC_3), U5.VIN, U6.9 (COM)
/CONFIG_SW: SW1.3, U1.28 (PC6)
/DOOR_EN: RN4.1 (R1.1), U1.33 (PA7)
/DOOR_EXTEND: J7.2, U4.2 (OUTA_1), U4.15 (OUTA_2)
/DOOR_INA: RN4.6 (R3.2), U1.35 (PA5)
/DOOR_INB: RN4.4 (R2.2), U1.34 (PA6)
/DOOR_RETRACT: J7.1, U4.7 (OUTB_1), U4.10 (OUTB_2)
/DOOR_SW: C4.1, R6.1, U1.17 (PD3)
/K1 RESET: U1.18 (PD4), U6.2 (I2)
/K1 SET: U1.19 (PD5), U6.1 (I1)
/K2 RESET: U1.21 (PD7), U6.4 (I4)
/K2 SET: U1.20 (PD6), U6.3 (I3)
/LED1: J9.4, U1.40 (PA0)
/LED2: R5.1, U1.39 (PA1)
/LOCK_EN: RN4.8 (R4.2), U1.36 (PA4)
/LOCK_EXTEND: J6.2, U3.2 (OUTA_1), U3.15 (OUTA_2)
/LOCK_INA: RN4.12 (R6.2), U1.38 (PA2)
/LOCK_INB: RN4.10 (R5.2), U1.37 (PA3)
/MISO: J2.1 (MISO), U1.7 (PB6)
/MOSI: R11.1, U1.6 (PB5)
/RTC_INT: R4.2, U1.16 (PD2), U2.7 (~INT1/CLKOUT)
/RXD: J3.3, U1.14 (PD0)
/SCK: R13.1, U1.8 (PB7)
/SCL: R2.2, U1.22 (PC0), U2.6 (SCL)
/SDA: R3.2, U1.23 (PC1), U2.5 (SDA)
/TXD: J3.2, U1.15 (PD1)
//RESET: R1.2, R7.1, SW3.2, U1.9 (~RESET)
GND: BT1.N, C1.2, C2.2, C3.2, C4.2, C5.2, C6.2, C7.2, C8.2, C9.2, C10.2, C11.2, C12.2, C13.2, C14.2, J1.BLK, J2.6 (GND), J3.6, J9.3, RN2.1 (common), SW1.1, SW1.MH1, SW1.MH2, SW3.1, TVS1.1 (K), U1.11 (GND), U1.31 (GND), U2.4 (VSS), U3.1 (GNDA_1), U3.8 (GNDB_1), U3.9 (GNDB_2), U3.14 (SEL0), U3.16 (GNDA_2), U4.1 (GNDA_1), U4.8 (GNDB_1), U4.9 (GNDB_2), U4.14 (SEL0), U4.16 (GNDA_2), U5.GND_1 (GND), U5.GND_2 (GND), U6.8 (GND)
unnamed: D1.1 (KA), P1.4
unnamed: D1.2 (AK), P1.2
unnamed: J2.4 (MOSI), R11.2
unnamed: J2.3 (SCK), R13.2
unnamed: J2.5 (~RST), R7.2
unnamed: J4.1, K1.8
unnamed: J4.2, K1.5
unnamed: J6.1, U3.7 (OUTB_1), U3.10 (OUTB_2)
unnamed: J8.1, K2.8
unnamed: J8.2, K2.5
unnamed: J9.1, R6.2
unnamed: J9.2, R5.2
unnamed: K1.15 (RESET), U6.15 (O2)
unnamed: K1.16 (SET), U6.16 (O1)
unnamed: K2.15 (RESET), U6.13 (O4)
unnamed: K2.16 (SET), U6.14 (O3)
unnamed: P1.1, SW2.1
unnamed: P1.3, SW2.2
unnamed: RN2.2 (R1), RN4.2 (R1.2), U4.11 (PWM)
unnamed: RN2.3 (R2), RN4.3 (R2.1), U4.6 (INB)
unnamed: RN2.4 (R3), RN4.5 (R3.1), U4.3 (INA)
unnamed: RN2.5 (R4), RN4.7 (R4.1), U3.11 (PWM)
unnamed: RN2.6 (R5), RN4.9 (R5.1), U3.6 (INB)
unnamed: RN2.7 (R6), RN4.11 (R6.1), U3.3 (INA)
unnamed: C14.1, U1.32 (AREF)
unnamed: U2.1 (OSCI), Y1.1
unnamed: U2.2 (OSCO), Y1.2
unnamed: BT1.P, U2.3 (VBAT)

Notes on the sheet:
FL12DRG5

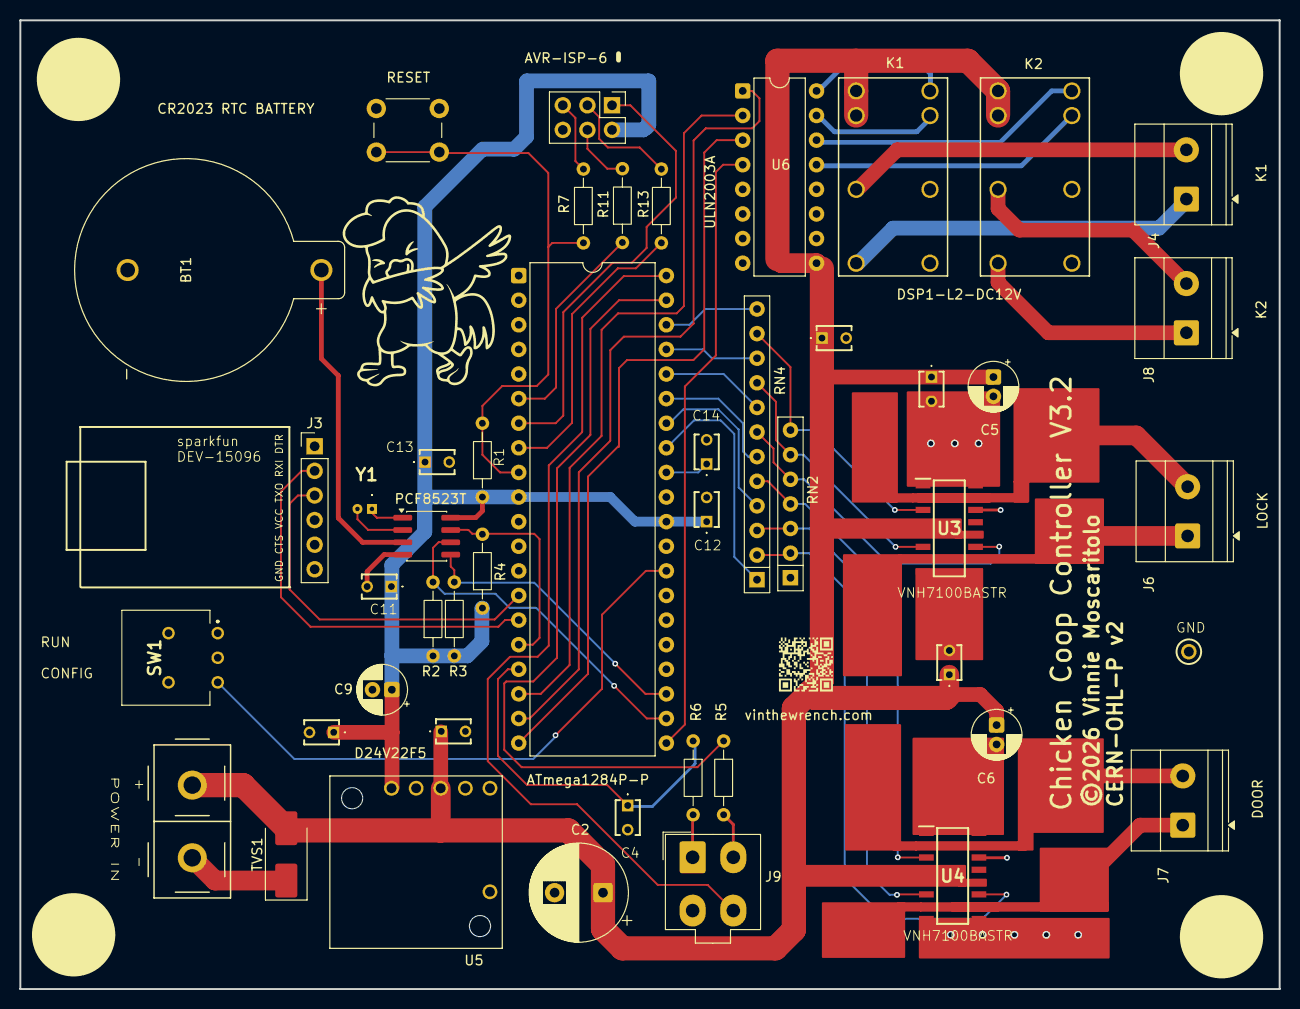
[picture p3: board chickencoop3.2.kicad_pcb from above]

Board: 2 copper layers, 130.0 x 100.0 mm, 47 parts (0 on the bottom side), 53 nets.

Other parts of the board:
TP3: GND; 5000

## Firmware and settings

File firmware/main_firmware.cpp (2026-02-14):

/*
 * main_firmware.cpp
 *
 * Chicken Coop Controller
 *
 * WAKE TRUTH:
 *   RTC INT → PD2 (INT0)
 *   LOW-level trigger
 *   SLEEP_MODE_PWR_DOWN
 *
 * Anything else is wrong.
 *
 * Updated: 2026-02-12
 */

#include <stdbool.h>
#include <stdint.h>
#include <util/delay.h>
#include <avr/io.h>
#include <avr/wdt.h>
#include <avr/interrupt.h>

#include "config.h"
#include "config_sw.h"

#include "console/console.h"
#include "console/mini_printf.h"

#include "uptime.h"
#include "rtc.h"
#include "solar.h"
#include "platform/uart.h"
#include "system_sleep.h"

#include "time_dst.h"

#include "scheduler.h"
#include "state_reducer.h"
#include "schedule_apply.h"

#include "devices/devices.h"
#include "devices/led_state_machine.h"
#include "devices/door_state_machine.h"

#include "platform/gpio_avr.h"
#include "platform/i2c.h"


/* ============================================================================
 * INT0 WAKE (PD2)
 * ========================================================================== */

ISR(INT0_vect)
{
    EIMSK &= (uint8_t)~(1u << INT0);
}

static volatile uint8_t g_door_event = 0;

ISR(INT1_vect)
{
    EIMSK &= (uint8_t)~(1u << INT1);
    g_door_event = 1u;
}


/* ============================================================================
 * TIME HELPERS
 * ========================================================================== */

static inline uint16_t minute_of_day(int h, int m)
{
    return (uint16_t)((uint16_t)h * 60u + (uint16_t)m);
}

static inline uint16_t next_minute(uint16_t now_min)
{
    return (uint16_t)((now_min + 1u) % 1440u);
}

static inline uint16_t strictly_future_minute(uint16_t now_min,
                                              uint16_t target_min)
{
    if (target_min <= now_min)
        return next_minute(now_min);
    return target_min;
}


/* ============================================================================
 * RESET CAUSE
 * ========================================================================== */

static uint8_t g_reset_flags;

static void reset_cause_capture_early(void)
{
    g_reset_flags = MCUSR;
    MCUSR = 0;
    wdt_disable();

    MCUCR |= _BV(JTD);
    MCUCR |= _BV(JTD);
}

static void reset_cause_debug_print(void)
{
    if (g_reset_flags & _BV(PORF))  mini_printf("RESET: Power On\n");
    if (g_reset_flags & _BV(BORF))  mini_printf("RESET: Brown-Out\n");
    if (g_reset_flags & _BV(WDRF))  mini_printf("RESET: Watchdog\n");
}


/* ============================================================================
 * MAIN
 * ========================================================================== */

 int main(void)
 {
     bool rtc_valid = false;

     reset_cause_capture_early();

     if (g_reset_flags & _BV(BORF)) {
         _delay_ms(50);
     }

     uart_init();
     uptime_init();
     coop_gpio_init();

     if (!i2c_init(100000)) {
         led_state_machine_init();
         led_state_machine_set(LED_BLINK, LED_RED);
         for (;;) {
             led_state_machine_tick(uptime_millis());
         }
     }

     rtc_init();

    rtc_valid = rtc_validate_at_boot();

     system_sleep_init();
     sei();

     device_init();
     scheduler_init();
     (void)config_load(&g_cfg);

     led_state_machine_set(LED_BLINK, LED_GREEN, 4);

     int last_y  = -1;
     int last_mo = -1;
     int last_d  = -1;

     uint16_t last_minute = 0xFFFF;
     uint32_t last_etag   = 0;

     struct solar_times sol;
     bool have_sol = false;

     bool in_config_mode = false;

     uint8_t  door_debounce_active   = 0;
     uint32_t door_debounce_start_ms = 0;

     bool force_time_read = true;

     int cached_y = 0, cached_mo = 0, cached_d = 0;
     int cached_h = 0, cached_m = 0, cached_s = 0;

     for (;;) {

         uint32_t now_ms = uptime_millis();
         device_tick(now_ms);

         /* ------------------------------------------------------
          * CONFIG switch
          * ------------------------------------------------------ */

         bool raw = config_sw_state();

         if (raw != in_config_mode) {

             _delay_ms(75);

             if (config_sw_state() == raw) {

                 in_config_mode = raw;

                 if (in_config_mode) {
                     console_init();
                     reset_cause_debug_print();
                 } else {
                     mini_printf("Exiting console\n\n");
                     console_flush();
                     console_terminal_shutdown();
                 }
             }
         }

         if (in_config_mode) {
             console_poll();
         }

         /* ------------------------------------------------------
          * Door ISR latch
          * ------------------------------------------------------ */

         if (g_door_event && !door_debounce_active) {
             g_door_event = 0u;
             door_debounce_active = 1u;
             door_debounce_start_ms = now_ms;
         }

         if (door_debounce_active) {
             if ((uint32_t)(now_ms - door_debounce_start_ms) >= 20u) {
                 door_debounce_active = 0u;
                 if (gpio_door_sw_is_asserted()) {
                     door_sm_toggle();
                 }
             }
         }

         if (!gpio_door_sw_is_asserted() && !door_debounce_active) {
             EIFR  |= (uint8_t)(1u << INTF1);
             EIMSK |= (uint8_t)(1u << INT1);
         }

         /* ------------------------------------------------------
          * RTC required
          * ------------------------------------------------------ */

          if(rtc_time_is_set()) {
              if(!rtc_valid) rtc_valid = true;
          }
          else
         {
             led_state_machine_set(LED_BLINK, LED_RED);
             continue;
         }

         /* ------------------------------------------------------
          * Read RTC ONLY when needed
          * ------------------------------------------------------ */

         if (force_time_read) {

             rtc_get_time(&cached_y,
                          &cached_mo,
                          &cached_d,
                          &cached_h,
                          &cached_m,
                          &cached_s);

             force_time_read = false;
         }

         uint16_t now_minute = minute_of_day(cached_h, cached_m);
         uint32_t cur_etag   = schedule_etag();

         bool minute_changed = (now_minute != last_minute);
         bool schedule_dirty = (cur_etag != last_etag);

         /* ------------------------------------------------------
          * On minute change, refresh RTC + scheduler
          * ------------------------------------------------------ */

         if (minute_changed || schedule_dirty) {

             /* Re-read RTC once to get accurate minute boundary */
             rtc_get_time(&cached_y,
                          &cached_mo,
                          &cached_d,
                          &cached_h,
                          &cached_m,
                          &cached_s);

             now_minute = minute_of_day(cached_h, cached_m);

             last_minute = now_minute;
             last_etag   = cur_etag;

             /* ---- Solar recompute if date changed ---- */

             if (cached_y != last_y ||
                 cached_mo != last_mo ||
                 cached_d != last_d) {

                 have_sol = false;

                 if (g_cfg.latitude_e4 != 0 ||
                     g_cfg.longitude_e4 != 0) {

                     double lat = (double)g_cfg.latitude_e4  / 10000.0;
                     double lon = (double)g_cfg.longitude_e4 / 10000.0;

                     int tz = g_cfg.tz;
                     if (g_cfg.honor_dst &&
                         is_us_dst(cached_y,
                                   cached_mo,
                                   cached_d,
                                   cached_h))
                         tz += 1;

                     have_sol = solar_compute(
                         cached_y, cached_mo, cached_d,
                         lat, lon,
                         (int8_t)tz,
                         &sol
                     );
                 }

                 scheduler_update_day(
                     cached_y, cached_mo, cached_d,
                     have_sol ? &sol : NULL,
                     have_sol
                 );

                 last_y  = cached_y;
                 last_mo = cached_mo;
                 last_d  = cached_d;
             }

             /* ---- Apply schedule ---- */

             struct reduced_state rs;

             size_t used = 0;
             const Event *events = config_events_get(&used);

             if (events && used > 0) {

                 state_reducer_run(
                     events,
                     MAX_EVENTS,
                     have_sol ? &sol : NULL,
                     now_minute,
                     &rs
                 );

                 schedule_apply(&rs);
             }
         }

         /* ------------------------------------------------------
          * Sleep only in RUN mode
          * ------------------------------------------------------ */

         if (in_config_mode)
             continue;

         if (devices_busy() ||
             door_debounce_active ||
             g_door_event)
             continue;

         uint16_t next_min;
         uint16_t wake_min;

         if (scheduler_next_event_minute(&next_min))
             wake_min = strictly_future_minute(now_minute, next_min);
         else
             wake_min = next_minute(now_minute);

         (void)rtc_alarm_set_minute_of_day(wake_min);
         system_sleep_until(wake_min);

         /* After wake, force time read next loop */
         force_time_read = true;

         if (gpio_rtc_int_is_asserted())
             rtc_alarm_clear_flag();

         EIFR |= (uint8_t)((1u << INTF0) | (1u << INTF1));

         if (!gpio_rtc_int_is_asserted())
             EIMSK |= (uint8_t)(1u << INT0);

         if (!gpio_door_sw_is_asserted())
             EIMSK |= (uint8_t)(1u << INT1);
     }
 }

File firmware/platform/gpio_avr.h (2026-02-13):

/*
 * gpio_avr.h
 *
 * Project: Chicken Coop Controller
 * Purpose: AVR GPIO pin definitions and low-level hardware mapping
 *
 * This header defines the canonical mapping between AVR GPIO pins
 * and physical hardware functions on the Chicken Coop Controller PCB.
 *
 * IMPORTANT DESIGN RULES:
 *  - All mappings in this file are LOCKED to the board schematic.
 *  - Do NOT rename, repurpose, or reassign any pin here unless
 *    the PCB schematic and layout are changed accordingly.
 *  - Higher-level code MUST treat these as hardware truth.
 *
 * SAFETY NOTE:
 *  - Several pins in this file control motors, relays, and solenoids.
 *  - Incorrect initialization or prolonged activation CAN damage hardware.
 *  - All outputs must be initialized to a known-safe OFF state at boot.
 *
 * Updated:
 *   (fill in date when pin mapping changes — not for code-only edits)
 */

#pragma once

/* --------------------------------------------------------------------------
 * Status LED Outputs
 * --------------------------------------------------------------------------
 *
 * These pins drive the front-panel red/green status LED through
 * external driver hardware.
 *
 * Naming convention:
 *  - LED_IN1 / LED_IN2 match the schematic net names.
 *  - Color association is documented for human clarity only.
 *
 * NOTE:
 *  - Do NOT change these names unless the hardware wiring changes.
 * -------------------------------------------------------------------------- */
 #define LED_IN1_BIT   PA1   /* RED   */
 #define LED_IN2_BIT   PA0   /* GREEN */

/* --------------------------------------------------------------------------
 * Door Motor H-Bridge Control (VNH7100BASTR)
 * --------------------------------------------------------------------------
 *
 * This H-bridge drives the main chicken coop door actuator.
 *
 * Electrical notes:
 *  - The door actuator includes internal end-of-travel limit switches.
 *  - Despite this, firmware MUST still enforce a maximum travel time
 *    as a fail-safe against wiring or switch failure.
 *
 * Pin behavior:
 *  - DOOR_EN   : Enables/disables the H-bridge (active HIGH)
 *  - DOOR_INA  : Direction control A
 *  - DOOR_INB  : Direction control B
 *
 * Reset behavior:
 *  - DOOR_EN MUST be driven LOW at boot.
 *  - INA/INB MUST be driven LOW at boot.
 *
 * -------------------------------------------------------------------------- */
/* DOOR_INA -> PF5 (physical pin 38) */
/* DOOR_INB -> PF6 (physical pin 37) */
/* DOOR_EN  -> PF7 (physical pin 36) */
#define DOOR_INA_BIT   PA5
#define DOOR_INB_BIT   PA6
#define DOOR_EN_BIT    PA7

/* --------------------------------------------------------------------------
 * Door Lock Actuator H-Bridge (VNH7100BASTR)
 * --------------------------------------------------------------------------
 *
 * This H-bridge drives the door LOCK actuator.
 *
 * CRITICAL SAFETY WARNING:
 *  - The lock actuator does NOT have end-of-travel limit switches.
 *  - It MUST be driven using a SHORT, FIXED-DURATION PULSE ONLY.
 *  - Continuous drive WILL overheat and destroy the actuator.
 *
 * Firmware requirements:
 *  - LOCK_EN MUST never be left asserted continuously.
 *  - A hard maximum pulse time (lock_pulse_ms) is mandatory.
 *  - Lock control must be edge-triggered, not state-held.
 *
 * JTAG NOTE:
 *  - LOCK_EN uses PF4, which is a JTAG pin by default.
 *  - Runtime JTAG disable is REQUIRED before driving this pin.
 * -------------------------------------------------------------------------- */
/* LOCK_INA -> PF0 */
/* LOCK_INB -> PF1 */
/* LOCK_EN  -> PF4 */
#define LOCK_INA_BIT   PA2
#define LOCK_INB_BIT   PA3
#define LOCK_EN_BIT    PA4

/* --------------------------------------------------------------------------
 * Latching Relay Outputs
 * --------------------------------------------------------------------------
 *
 * These pins drive a dual latching relay via external driver circuitry.
 *
 * Relay behavior:
 *  - SET and RESET are separate coils.
 *  - Coils must be pulsed briefly; they must NOT be held energized.
 *
 * Firmware requirements:
 *  - All relay outputs must default to OFF at boot.
 *  - Pulse duration must be limited in software.
 * -------------------------------------------------------------------------- */
#define RELAY1_SET_BIT    PD5
#define RELAY1_RESET_BIT  PD4
#define RELAY2_SET_BIT    PD6
#define RELAY2_RESET_BIT  PD7
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

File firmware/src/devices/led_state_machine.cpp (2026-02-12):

/*
 * led_state_machine.cpp
 *
 * Project: Chicken Coop Controller
 * Purpose: Door status LED state machine
 *
 * Notes:
 *  - Non-blocking at the state-machine level
 *  - Software PWM carrier is driven by repeated door_led_tick() calls
 *  - Pulse envelope is rate-limited for smooth breathing
 *
 * Extended:
 *  - Blink/Pulse may run finite number of cycles
 *  - count = 0 → infinite
 *  - count > 0 → run exactly N cycles then auto-off
 */

#include "led_state_machine.h"
#include "door_led.h"

#include <stdint.h>
#include <stdbool.h>

/* --------------------------------------------------------------------------
 * Timing
 * -------------------------------------------------------------------------- */

#define BLINK_PERIOD_MS   250u
#define PULSE_PERIOD_MS  1500u
#define PWM_TICKS_PER_MS  48u

/* --------------------------------------------------------------------------
 * Internal state
 * -------------------------------------------------------------------------- */

static led_mode_t  g_mode  = LED_OFF;
static led_color_t g_color = LED_GREEN;

/* Optional finite-cycle support */
static uint16_t g_cycles_remaining = 0;   /* 0 = infinite */
static uint16_t g_cycle_counter    = 0;   /* counts completed cycles */

static uint32_t g_blink_t0_ms = 0;
static bool     g_led_on      = false;

/* Pulse timing (in PWM ticks) */
static uint32_t g_pulse_last_ticks = 0;
static uint8_t  g_pulse_step       = 0;
static uint32_t g_pwm_ticks        = 0;
static uint32_t g_pulse_err        = 0;

/* --------------------------------------------------------------------------
 * Perceptual breathing envelopes
 * -------------------------------------------------------------------------- */

static const uint8_t pulse_lut_green[] = {
      0,  1,  2,  4,  7, 11, 16, 22,
     29, 37, 46, 56, 67, 79, 92,106,
    121,137,154,172,191,211,232,255,
    232,211,191,172,154,137,121,106,
     92, 79, 67, 56, 46, 37, 29, 22,
     16, 11,  7,  4,  2,  1
};

static const uint8_t pulse_lut_red[] = {
      0,  4,  7, 11, 16, 23, 31, 40,
     50, 61, 73, 86,100,115,131,148,
    166,185,205,225,245,252,255,255,
    252,245,225,205,185,166,148,131,
    115,100, 86, 73, 61, 50, 40, 31,
     23, 16, 11,  7,  4
};

#define PULSE_STEPS_GREEN ((uint8_t)sizeof(pulse_lut_green))
#define PULSE_STEPS_RED   ((uint8_t)sizeof(pulse_lut_red))

/* --------------------------------------------------------------------------
 * Helpers
 * -------------------------------------------------------------------------- */

static inline void led_apply(bool on, uint8_t duty)
{
    if (!on) {
        door_led_off();
        return;
    }

    if (g_color == LED_GREEN)
        door_led_green_pwm(duty);
    else
        door_led_red_pwm(duty);
}

static void door_led_pwm_service(uint32_t now_ms)
{
    static uint32_t last_ms = 0;

    uint32_t elapsed = now_ms - last_ms;
    if (elapsed == 0)
        return;

    last_ms = now_ms;

    uint32_t ticks = elapsed * PWM_TICKS_PER_MS;

    const uint32_t MAX_TICKS = 10u * PWM_TICKS_PER_MS;
    if (ticks > MAX_TICKS)
        ticks = MAX_TICKS;

    while (ticks--) {
        door_led_tick();
        g_pwm_ticks++;
    }
}

/* --------------------------------------------------------------------------
 * Public API
 * -------------------------------------------------------------------------- */

/**
 * @brief Initialize LED state machine.
 */
void led_state_machine_init(void)
{
    g_mode              = LED_OFF;
    g_color             = LED_GREEN;
    g_cycles_remaining  = 0;
    g_cycle_counter     = 0;

    g_blink_t0_ms       = 0;
    g_led_on            = false;

    g_pulse_last_ticks  = 0;
    g_pulse_step        = 0;
    g_pwm_ticks         = 0;
    g_pulse_err         = 0;

    door_led_init();
    door_led_off();
}


/**
 * @brief Set LED mode with optional finite cycle count.
 *
 * @param mode   LED mode
 * @param color  LED color
 * @param count  Number of cycles (0 = infinite)
 */
 void led_state_machine_set(led_mode_t mode,
                            led_color_t color,
                            uint16_t count)
 {
     g_mode             = mode;
     g_color            = color;
     g_cycles_remaining = count;
     g_cycle_counter    = 0;

     g_blink_t0_ms      = 0;
     g_led_on           = false;

     g_pulse_last_ticks = 0;
     g_pulse_step       = 0;
     g_pulse_err        = 0;

     if (mode == LED_OFF) {
         door_led_off();
         return;
     }

     if (mode == LED_ON) {
         g_led_on = true;
         led_apply(true, 255);
         return;
     }

     if (mode == LED_PULSE) {

         /* Immediately light at full brightness */
         g_led_on = true;
         led_apply(true, 255);

         /* Start pulse from peak so it decays immediately */
         if (color == LED_GREEN)
             g_pulse_step = PULSE_STEPS_GREEN - 1;
         else
             g_pulse_step = PULSE_STEPS_RED - 1;

         g_pulse_last_ticks = g_pwm_ticks;
         g_pulse_err = 0;
     }
 }

/**
 * @brief Backward-compatible overload (infinite cycles).
 */
void led_state_machine_set(led_mode_t mode,
                           led_color_t color)
{
    led_state_machine_set(mode, color, 0);
}

bool led_state_machine_is_on(void)
{
    return g_led_on;
}
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

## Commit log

2026-01-05 check in hardware
    [chickencoop3.kicad_pcb, chickencoop3.kicad_sch]
2026-01-08 Scheduler refactor: unify host/firmware execution, add ETag, fix time sampling, enable RTC sleep
    Host and firmware now run identical scheduler logic.
    Schedule reevaluates on minute tick or config/event changes.
    Firmware sleeps via RTC alarm between events.
    [console_cmds.cpp, main_firmware.cpp]
2026-01-17 firmware is working in console -
    [chickencoop3.1.kicad_pcb, chickencoop3.1.kicad_sch, chickencoop3.kicad_pcb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]
2026-01-20 version 3.2 HW - using ATmega1284P now
    [chickencoop3.2.csv, chickencoop3.2.kicad_pcb, chickencoop3.2.kicad_sch]
2026-02-02 more updates
    [chickencoop3.1.kicad_pcb, chickencoop3.1.kicad_sch, chickencoop3.kicad_pcb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]
2026-02-04 moved HW
    [chickencoop3.kicad_pcb, chickencoop3.kicad_sch]
2026-02-04 Checkpoint: working LED pulse, RTC, scheduler, and door control (lock unsafe)
2026-02-07 rtc: disable PCF8523 CLKOUT and stabilize INT behavior
    - Explicitly set COF=111 in REG 0x0F during rtc_init()
    - Prevent unintended 32.768 kHz square wave on INT/CLKOUT
    - Confirm I2C register writes and readbacks
    - Establish clean baseline for deterministic alarm + sleep debugging
    Shop session validation:
    - Verified CLKOUT disable on scope
    - Confirmed INT line high when idle
    - RTC timekeeping stable
    [console_cmds.cpp, main_firmware.cpp, rtc.cpp]
2026-02-07 forgot to restore uptime_init this is critical for device timing
2026-02-07 AI gave me bad set time code -- revert to what I know
    [main_firmware.cpp, rtc.cpp]
2026-02-12 still messing with RTC issues
    [rtc.cpp]
2026-02-13 directory cleanup now that we do firmware builds only
    [chickencoop3.1.kicad_pcb, chickencoop3.1.kicad_sch, chickencoop3.kicad_pcb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]
2026-02-14 more rtc, scheduler and cmd fixes
    [console_cmds.cpp, main_firmware.cpp, rtc.cpp]

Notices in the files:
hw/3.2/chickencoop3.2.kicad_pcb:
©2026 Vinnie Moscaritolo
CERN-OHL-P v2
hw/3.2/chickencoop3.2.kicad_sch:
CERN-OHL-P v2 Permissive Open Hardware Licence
